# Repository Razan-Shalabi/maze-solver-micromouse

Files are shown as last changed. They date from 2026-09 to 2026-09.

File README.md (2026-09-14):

# Toots — Autonomous Micromouse Robot

An autonomous maze-solving robot built on an ESP32, using a floodfill algorithm, PID-corrected motor control, and time-of-flight wall sensing to navigate an 8×8 maze without human input.

**Team:** Razan Shalabi, Shatha Abualrub, Lara Daifallah, Ghada Swalha

**Instructor:** Wasel Ghanem

**Institution:** Birzeit University

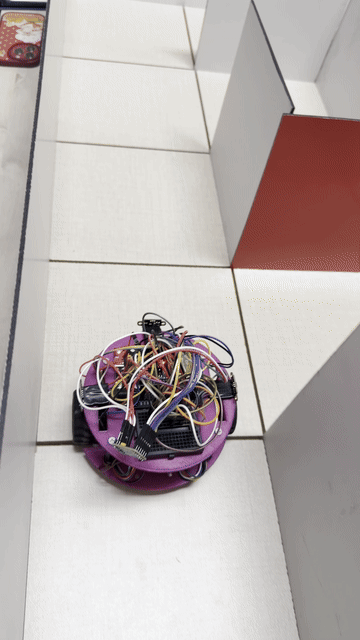
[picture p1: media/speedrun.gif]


*Toots completing a speed-run pass after the exploration phase.*

## Overview

Toots explores an 8×8 maze, builds a map of its walls, and computes the shortest path to the center. It then executes that path at higher speed on a return run. Core capabilities:

- Real-time wall detection using three VL53L0X time-of-flight sensors
- Wheel odometry via interrupt-driven magnetic encoders
- Shortest-path planning with a floodfill (BFS) solver
- PID-corrected differential drive to maintain heading between walls
- A web dashboard, served directly from the ESP32, for live monitoring and parameter tuning

## Documentation

| Resource | Description |
|---|---|
| [`hardware/README.md`](hardware/README.md) | Full parts list, pin map, and per-component wiring notes |
| [`hardware/3d-models/`](hardware/3d-models/README.md) | Chassis STL file and Fusion 360 source |
| [`software/README.md`](software/README.md) | Firmware architecture, run modes, dashboard API, tunable parameters |
| [Trello board](https://trello.com/invite/b/69e2683745c4a1b255d148a3/ATTI001aa2c3a295a99a65e10da04925d9e88B10C430/interface-project) | Full project build log |

## Hardware Summary

| Component | Part | Role |
|---|---|---|
| MCU | ESP32 Dev Kit | Runs firmware and web dashboard |
| Motor driver | DRV8833 | Drives both motors |
| Motors | N20 DC with magnetic encoder, 6V, 530 RPM | Differential drive with speed feedback |
| Distance sensors | VL53L0X ×3 | Front, left, right wall detection |
| Chassis | Custom 3D-printed | Sized to maze cell constraints |

Full specifications and wiring: [`hardware/README.md`](hardware/README.md)

## How It Works

**Wall sensing.** Three ToF sensors feed a correction function that keeps the robot centered between walls, or at a fixed offset from a single wall, while driving forward.

**Motion tracking.** Interrupt-driven encoder ticks on both wheels are compared through a PID loop to keep the two motors synchronized.

**Path planning.** A floodfill (BFS) solver computes the shortest path to the maze center as the robot explores, and recomputes as new walls are discovered.

**Connectivity.** WiFi credentials are never hardcoded. On first boot, the ESP32 opens a setup access point (`TOOTs-Setup`); the operator selects a network and enters credentials once, which are then stored to flash.

**Monitoring.** A dashboard served at `http://toots.local` shows live sensor data, current position, and run mode, with controls to tune PID, turn timing, and wall-following parameters without re-flashing.

Full technical detail: [`software/README.md`](software/README.md)

## Getting Started

**Requirements:**
- Arduino IDE with the ESP32 board package
- Libraries: `WiFiManager` (tzapu), `VL53L0X`, `ESPmDNS` (bundled with the ESP32 core)

**Steps:**
1. Open `software/toots.ino` in the Arduino IDE
2. Select the correct ESP32 board and port
3. Upload
4. On first boot, connect to the `TOOTs-Setup` network and enter your WiFi credentials
5. Open `http://toots.local` (or the IP shown in Serial output) to access the dashboard

## Repository Structure

```
maze-solver-micromouse/
├── README.md
├── media/
│   └── speedrun.gif
├── software/
│   ├── README.md
│   └── toots.ino
└── hardware/
    ├── README.md
    ├── components/
    └── 3d-models/
```

## Background

The project began with component selection and procurement, followed by chassis design in Fusion 360, built to fit within maze cell constraints while keeping weight low enough not to strain the motors. The chassis was 3D-printed and assembled alongside firmware development.

The floodfill solving logic was validated in simulation before deployment to hardware, to confirm correctness of the algorithm independent of sensor noise or mechanical variance.

A full build log, including design decisions and iteration history, is maintained on the [Trello board](https://trello.com/invite/b/69e2683745c4a1b255d148a3/ATTI001aa2c3a295a99a65e10da04925d9e88B10C430/interface-project).

## License

Submitted as academic coursework. The code is available to study and reference.

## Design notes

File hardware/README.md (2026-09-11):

# Hardware

Toots is built around an ESP32, driving two N20 motors through a DRV8833, sensing walls with three VL53L0X ToF sensors, and tracking movement with magnetic wheel encoders.

## Components

| Photo | Component | Part | Role | Docs |
|---|---|---|---|---|
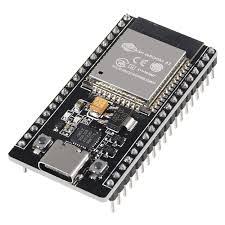
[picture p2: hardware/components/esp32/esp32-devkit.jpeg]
|  | MCU | ESP32 Dev Kit (30-pin) | Runs firmware + web dashboard | [→](components/esp32/README.md) |
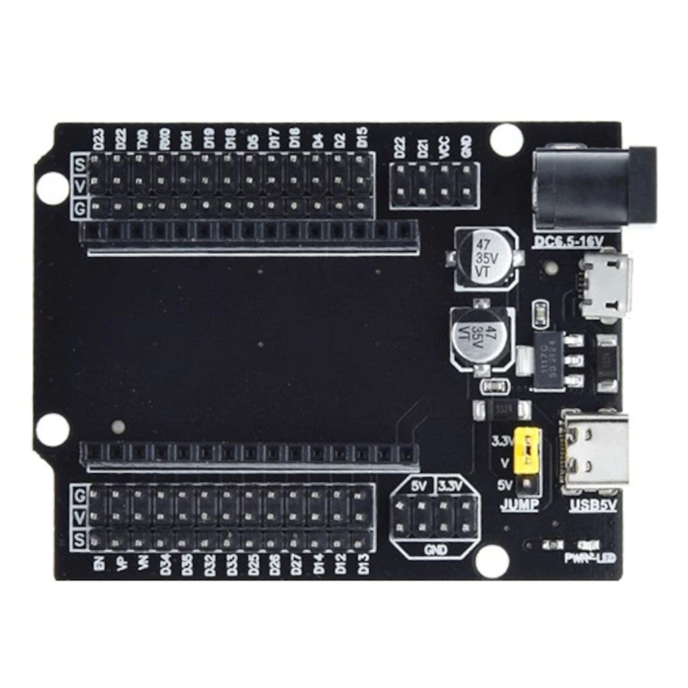
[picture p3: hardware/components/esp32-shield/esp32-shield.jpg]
|  | Expansion Board | ESP32 30-pin Shield | Breaks out GPIO for wiring | [→](components/esp32-shield/README.md) |
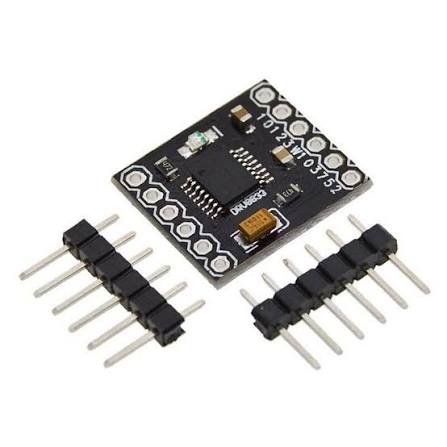
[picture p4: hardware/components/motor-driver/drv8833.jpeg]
|  | Motor Driver | DRV8833 (2-channel) | Drives both N20 motors | [→](components/motor-driver/README.md) |
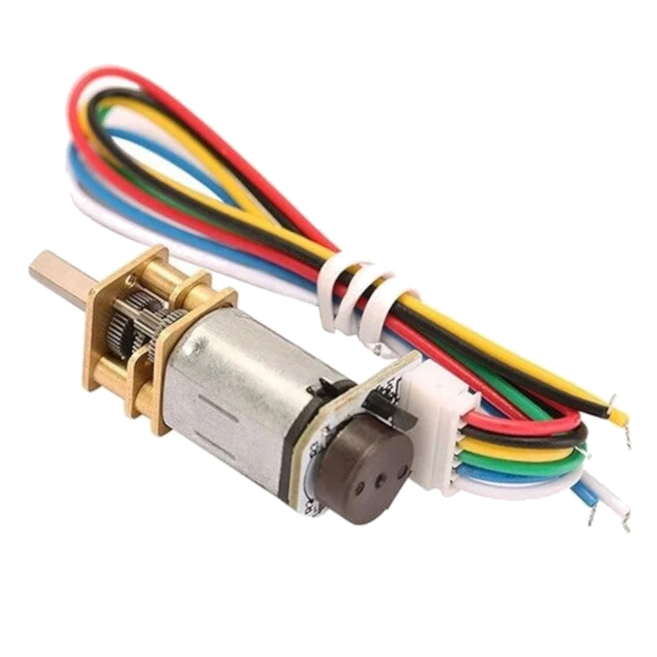
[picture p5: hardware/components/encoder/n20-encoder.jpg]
|  | Motors | N20 DC w/ Encoder, 6V 530 RPM | Differential drive + speed feedback | [→](components/encoder/README.md) |
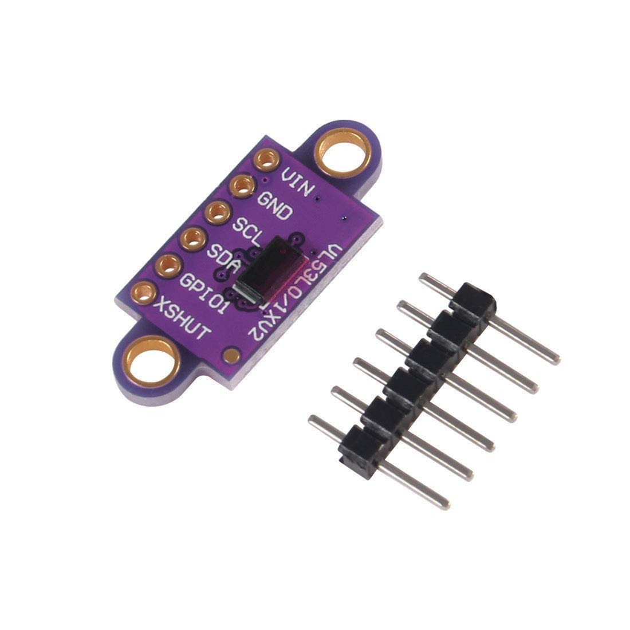
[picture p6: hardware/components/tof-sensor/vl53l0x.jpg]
|  | ToF Sensors ×3 | VL53L0X | Wall detection: front, left, right | [→](components/tof-sensor/README.md) |
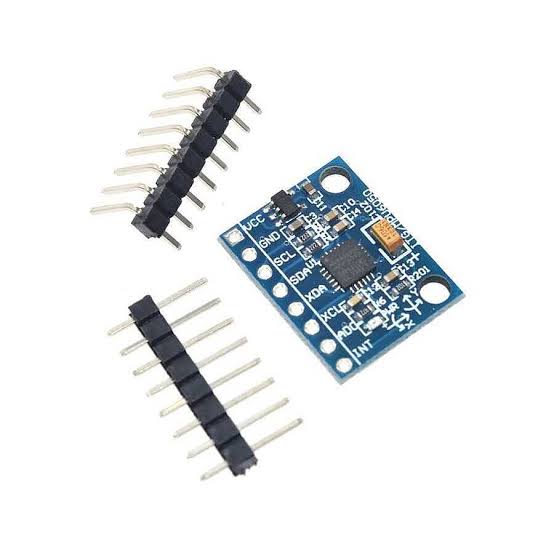
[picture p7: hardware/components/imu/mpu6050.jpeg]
|  | IMU | MPU-6050 | On board, not yet used in firmware | [→](components/imu/README.md) |
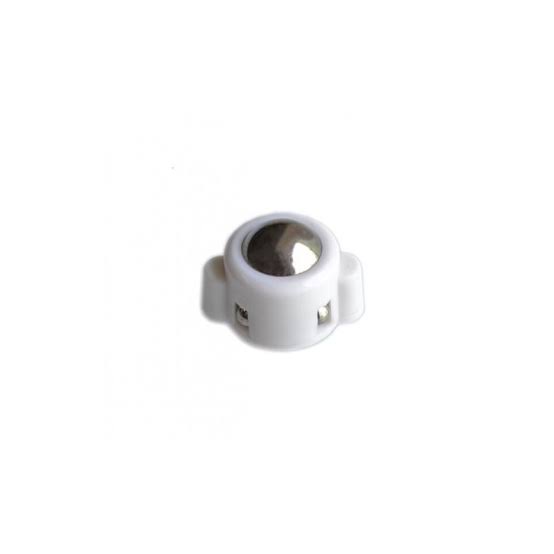
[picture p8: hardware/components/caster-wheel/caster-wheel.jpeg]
|  | Caster Wheel | Small Ball Caster | Third point of contact | [→](components/caster-wheel/README.md) |
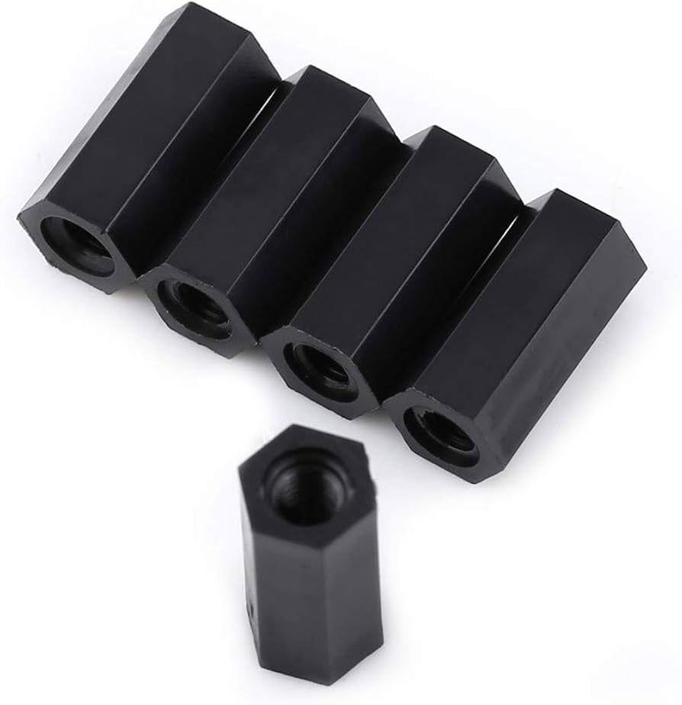
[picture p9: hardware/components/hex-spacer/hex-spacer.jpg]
|  | Standoffs | M3 Nylon Hex Spacer | Chassis layer mounting | [→](components/hex-spacer/README.md) |
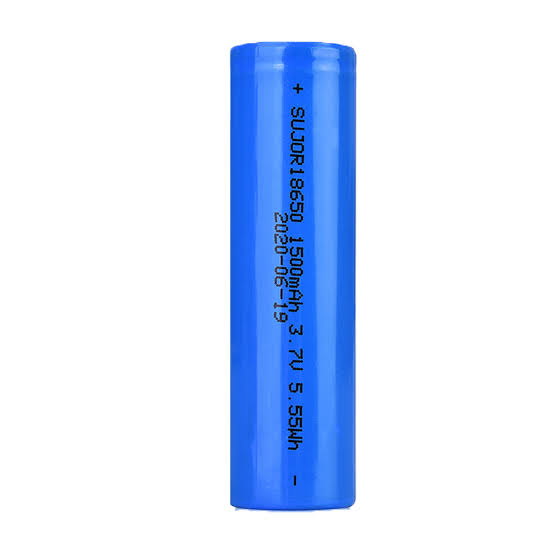
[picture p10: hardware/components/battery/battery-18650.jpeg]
|  | Battery | 18650 Li-ion | Main power | [→](components/battery/README.md) |
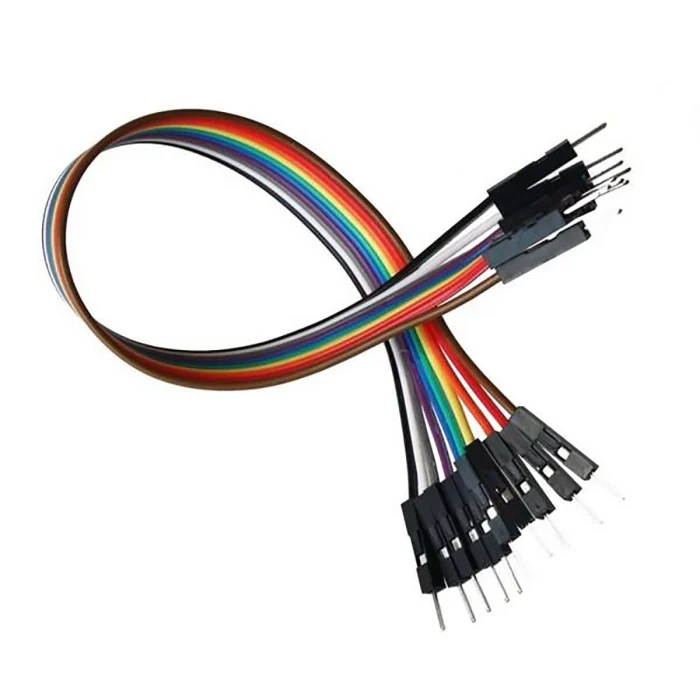
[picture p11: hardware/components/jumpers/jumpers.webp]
|  | Wiring | Jumper Wires | Sensor & module connections | [→](components/jumpers/README.md) |

## Pin Map

| Function | GPIO |
|---|---|
| Left motor IN1 / IN2 | 14 / 12 |
| Right motor IN3 / IN4 | 13 / 15 |
| Left encoder C1 / C2 | 34 / 35 |
| Right encoder C1 / C2 | 32 / 33 |
| ToF I2C SDA / SCL | 21 / 22 |
| ToF Front / Left / Right XSHUT | 25 / 26 / 27 |

Click into any component above for wiring details, how it's used in the code, specs, and troubleshooting.

## 3D Models

The chassis STL and Fusion 360 source link are in [`3d-models/`](3d-models/README.md).

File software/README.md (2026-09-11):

# Software

Single-file ESP32 firmware (`toots.ino`) written in C++ with the Arduino framework. It handles sensing, motor control, maze solving, and serves a live web dashboard — all from one sketch.

## Run Modes

The robot operates as a state machine (`RunMode`), driven from `solverStep()` in the main loop:

| Mode | Trigger | What it does |
|---|---|---|
| `MODE_IDLE` | Default / after any run finishes | Motors stopped, waiting for a command |
| `MODE_SOLVE` | `solve` command | Explores the maze, mapping walls with floodfill as it goes |
| `MODE_RETURN` | `return` command | Floods back to the start cell |
| `MODE_SPEEDRUN` | `speedrun` command (requires a completed map + robot at start) | Runs the shortest known path at full speed |

## Core Logic

- **`getWallCorrection()`** — compares left/right ToF readings against `WALL_THRESHOLD` and `SIDE_TARGET_MM` to compute a steering correction, keeping the robot centered (or a fixed distance from one wall)
- **`moveContinuousForward()`** — the main driving loop: reads encoders, computes error between wheels, runs it through a PID controller (`Kp`, `Ki`, `Kd`), adds the wall correction and a fixed motor bias (`BASE_CORRECTION`), then calls `setMotor()`
- **`floodFill(toStart, onlyVisited)`** — BFS distance-field solver; recomputes as new walls are discovered
- **`turnLeft90()` / `turnRight90()` / `turn180()`** — time-based turns using calibrated delays, followed by `postTurnCalibration()` to re-align using side wall distances

## Web Dashboard API

Served from the ESP32 itself — no external server needed.

| Endpoint | Method | Purpose |
|---|---|---|
| `/` | GET | Serves the dashboard HTML/CSS/JS |
| `/data` | GET | Returns live JSON: position, sensor readings, mode, all tunable parameters |
| `/cmd?c=...` | GET | Sends a command — see table below |
| `/set?k=...&v=...` | GET | Live-tunes a parameter without re-flashing |

**Commands (`/cmd?c=`):**

| Command | Effect |
|---|---|
| `solve` | Start maze exploration |
| `return` | Return to start cell |
| `speedrun` | Run the fastest known path |
| `s` | Emergency stop |
| `startfwd` / `stopfwd` | Manual continuous forward drive |
| `left90` / `right90` / `turn180` | Manual single turn |
| `celltof` | Move forward exactly one cell |
| `reset` | Zero the encoders |
| `resetpose` | Reset (x, y, direction) to origin |
| `resetmaze` | Clear the entire wall map |
| `debug` | Plain-text status dump over HTTP |

## Tunable Parameters

All adjustable live via the dashboard (`/set`), no re-upload needed:

| Parameter | Default | Role |
|---|---|---|
| `BASE_SPEED` | 120 | Cruising motor speed |
| `MIN_SPEED` | 58 | Floor speed after correction |
| `TURN_SPEED` | 120 | Speed during turns |
| `Kp` / `Ki` / `Kd` | 3.0 / 0.005 / 0.5 | PID gains for straight-line motor sync |
| `BASE_CORRECTION` | 3 | Fixed bias compensating for motor mismatch |
| `TURN_DELAY_LEFT` / `RIGHT` / `180` | 700 / 435 / 790 ms | Calibrated turn durations |
| `CELL_TICKS` | 250 | Encoder ticks per maze cell |
| `WALL_THRESHOLD` | 200 mm | Distance below which a wall is "detected" |
| `FRONT_STOP` | 100 mm | Distance to treat front as blocked |
| `SIDE_TARGET_MM` | 45 mm | Target distance from a single side wall |
| `LEFT_OFFSET` / `RIGHT_OFFSET` | -70 / -10 | Per-sensor calibration offsets |

## Known Limitations / Next Steps

- **Single monolithic file** — all logic lives in one `.ino`. Splitting sensing, motor control, and maze-solving into separate modules (`.h`/`.cpp` files) would make it easier to test and extend.
- **MPU-6050 not yet integrated** — the IMU is on the board but unused; turns currently rely on fixed time delays + post-turn wall calibration rather than gyro feedback. Adding gyro-based heading correction is a natural next step to reduce drift.
- **No automated tests** — all tuning and validation happens live via the dashboard.

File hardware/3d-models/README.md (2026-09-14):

# 3D Models — Chassis

The robot's chassis was designed in-house in Fusion 360 and 3D-printed.

- **STL file:** [chassis.stl](chassis.stl) — ready to slice and print
- **Fusion 360 source (editable):** [View on Fusion 360](https://student395829.autodesk360.com/g/shares/SH28cd1QT2badd0ea72bd2512c9273c0f380)

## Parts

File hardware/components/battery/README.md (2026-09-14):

# Power: 18650 Li-ion Battery + Charger


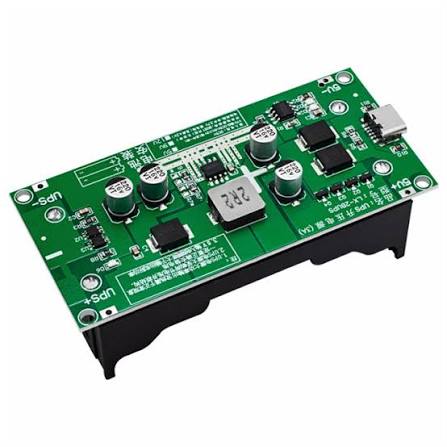
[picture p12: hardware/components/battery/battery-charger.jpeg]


## What is this?

Main power source for the robot, plus the module used to recharge it.

## Specs

- **Battery:** Li-ion 18650 cell
- **Charger:** Type-C, 15W, 3A charging module

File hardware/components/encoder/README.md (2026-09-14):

# N20 Magnetic Encoder



## What is this?

Reads wheel rotation from the N20 motors' built-in magnetic encoders using hardware interrupts. Used for distance tracking (how far each wheel has turned) and forward-motion PID correction.

## Hardware Connections

| Pin | Connects to | Role |
|---|---|---|
| C1 (Left) | ESP32 GPIO 34 | Main counting pin (interrupt on RISING) |
| C2 (Left) | ESP32 GPIO 35 | Direction detection |
| C1 (Right) | ESP32 GPIO 32 | Main counting pin (interrupt on RISING) |
| C2 (Right) | ESP32 GPIO 33 | Direction detection |
| VCC | 3.3V | Power |
| GND | Ground | Ground |

## How It Works

Interrupt-based counting — no polling:

```cpp
void IRAM_ATTR leftEncoderISR() {
  if (digitalRead(ENC_LEFT_C2) == HIGH)
    leftTicks++;
  else
    leftTicks--;
}
```

- Every rising edge on C1 fires the interrupt
- C2's state at that moment tells us the rotation direction (increments or decrements `leftTicks`/`rightTicks`)
- `resetEncoders()` zeroes both counters (used at the start of every move)

Ticks are read safely mid-motion by briefly disabling interrupts:

```cpp
noInterrupts();
dL = leftTicks;
dR = rightTicks;
interrupts();
```

## Specifications

- **Encoder resolution:** 530 PPR (pulses per revolution)
- **Motor:** N20 DC, 6V, 530 RPM

## Used In

- `moveContinuousForward()` — encoder difference (`dL + dR`) feeds the PID loop to keep both wheels in sync
- `CELL_TICKS` (currently `250`) — how many ticks equal one maze cell of forward travel

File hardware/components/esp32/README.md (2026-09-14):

# ESP32 Dev Kit (30-pin)



## What is this?

The brain of Toots — a dual-core microcontroller with built-in WiFi. It runs the maze-solving logic, drives the motors, reads all sensors, and hosts a live web dashboard for monitoring and tuning.

## Role in the System

- Runs the main control loop (`solverStep()`) — sensing, PID correction, floodfill decisions
- Hosts a `WebServer` on port 80 serving a live dashboard (position, sensor readings, tunable parameters)
- Connects to WiFi via **WiFiManager** — no hardcoded credentials. On first boot (or after a reset) it opens its own setup access point (`TOOTs-Setup`); connecting to that AP lets you pick your home WiFi and enter the password once, which is then saved to flash
- Reachable at `http://toots.local` via mDNS, or by IP shown in Serial output

## Hardware Connections

All sensor and motor pins connect here — see each component's own page (`encoder/`, `motor-driver/`, `tof-sensor/`) for exact pin numbers.

## Used In

- `setup()` — initializes motors, encoders, ToF sensors, WiFi, and the web server
- `loop()` — handles incoming web requests and runs the active solve/return/speedrun mode every 20ms

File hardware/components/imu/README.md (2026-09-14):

# MPU-6050 (Gyroscope + Accelerometer)



## What is this?

A 6-DoF IMU (gyroscope + accelerometer), included in the build for heading tracking.

This sensor is part of the hardware but **isn't wired into `toots.ino`'s logic yet** — the current heading/turn control relies entirely on the ToF wall-following (`getWallCorrection()`) and calibrated turn delays (`TURN_DELAY_LEFT`, `TURN_DELAY_RIGHT`, `TURN_DELAY_180`), not gyroscope data.

It's documented here for completeness and as a planned upgrade — adding gyro-based heading correction would reduce drift during turns compared to fixed time delays.

## Hardware Connections

| Pin | Connects to |
|---|---|
| SDA | ESP32 GPIO 21 (shared I2C bus with ToF sensors) |
| SCL | ESP32 GPIO 22 (shared I2C bus with ToF sensors) |
| VCC | 3.3V |
| GND | Ground |

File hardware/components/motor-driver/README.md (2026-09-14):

# DRV8833 Motor Driver



## What is this?

A 2-channel H-bridge driver that lets the ESP32 (3.3V logic) control both N20 motors independently — forward, reverse, and speed via PWM — since the ESP32's GPIO pins can't drive motors directly.

## Hardware Connections

| DRV8833 Pin | Connects to | Role |
|---|---|---|
| IN1 | ESP32 GPIO 14 | Left motor, direction A |
| IN2 | ESP32 GPIO 12 | Left motor, direction B |
| IN3 | ESP32 GPIO 13 | Right motor, direction A |
| IN4 | ESP32 GPIO 15 | Right motor, direction B |

## How It Works

```cpp
void setMotor(int leftSpeed, int rightSpeed) {
  rightSpeed = -rightSpeed;   // right motor is mounted flipped
  leftSpeed  = constrain(leftSpeed,  -255, 255);
  rightSpeed = constrain(rightSpeed, -255, 255);

  if (leftSpeed > 0)      { analogWrite(IN1, leftSpeed); analogWrite(IN2, 0); }
  else if (leftSpeed < 0) { analogWrite(IN1, 0); analogWrite(IN2, -leftSpeed); }
  else                    { analogWrite(IN1, 0); analogWrite(IN2, 0); }

  // same pattern for IN3/IN4 with rightSpeed
}
```

- Each wheel is driven by a pair of pins — PWM goes on whichever pin matches the desired direction, the other pin goes LOW
- Speed range is `-255` to `255` (negative = reverse)
- `rightSpeed` is inverted before use because the right motor is physically mounted in the opposite orientation to the left one — without this flip, "forward" on the right wheel would spin it backward

## Used In

- `setMotor(leftSpeed, rightSpeed)` is the single point everything else calls — PID output, wall correction, and turning all funnel through it
- `stopMotorsOnly()` → `setMotor(0, 0)`

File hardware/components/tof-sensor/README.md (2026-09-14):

# VL53L0X Time-of-Flight Sensors (×3)



## What is this?

Three laser-based distance sensors (front, left, right) that detect maze walls. They share one I2C bus, so each is given a unique address at boot.

## Hardware Connections

| Pin | Connects to | Role |
|---|---|---|
| SDA (all 3) | ESP32 GPIO 21 | Shared I2C data line |
| SCL (all 3) | ESP32 GPIO 22 | Shared I2C clock line |
| XSHUT (Front) | ESP32 GPIO 25 | Power-down control, used to assign address |
| XSHUT (Left) | ESP32 GPIO 26 | Power-down control, used to assign address |
| XSHUT (Right) | ESP32 GPIO 27 | Power-down control, used to assign address |

## How It Works

**Startup — assigning unique addresses:**

All VL53L0X sensors boot with the same default I2C address, so they can't just be wired in parallel and read directly. `setupToFs()` gets around this:

1. Pull all three XSHUT pins LOW (all sensors off)
2. Bring one sensor's XSHUT HIGH, initialize it, and reassign its I2C address (front → `0x30`, left → `0x31`, right → `0x32`)
3. Repeat for the next sensor

**Reading:**

```cpp
void readToFs() {
  int f = tofFront.readRangeContinuousMillimeters();
  ...
  if (tofFront.timeoutOccurred() || f <= 0 || f > 2000) {
    f = 2000;  // treat invalid reading as "no wall in range"
  }
  ...
}
```

`readToFsAveraged()` takes 3 readings 20ms apart and averages them for more stable values, used before turns.

## Used In

- `leftWall()`, `frontWall()`, `rightWall()` — compare distance against `WALL_THRESHOLD` (`200`mm)
- `getWallCorrection()` — steers the robot to stay centered between walls (or a fixed distance from a single wall) while driving forward
- Floodfill mapping — wall presence per cell is recorded from these readings

## Specifications

- **Front stop distance:** `FRONT_STOP` = 100mm 
- **Wall detection threshold:** `WALL_THRESHOLD` = 200mm
- **Side wall target distance:** `SIDE_TARGET_MM` = 45mm

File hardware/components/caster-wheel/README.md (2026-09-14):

# Small Ball Caster Wheel



## What is this?

A free-rolling ball caster used as the robot's third point of contact, opposite the two driven N20 wheels. Provides stable support without adding friction or needing its own motor.

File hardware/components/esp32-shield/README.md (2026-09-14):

# ESP32 30-Pin Expansion Board



## What is this?

A breakout/prototyping shield that sits under the ESP32 dev kit, breaking each GPIO pin out to a more accessible screw terminal or header — makes wiring the motor driver, encoders, and sensors more secure than jumping directly off the ESP32's pins.

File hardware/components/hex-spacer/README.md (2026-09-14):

# M3 Nylon Hex Spacer



## What is this?

Standoffs used to mount and space the chassis layers (e.g. separating the main board layer from the sensor/battery layer). M3 thread, female-to-female.

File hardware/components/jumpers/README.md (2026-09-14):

# Jumper Wires



## What is this?

Used for all point-to-point wiring between the ESP32, motor driver, encoders, and ToF sensors.

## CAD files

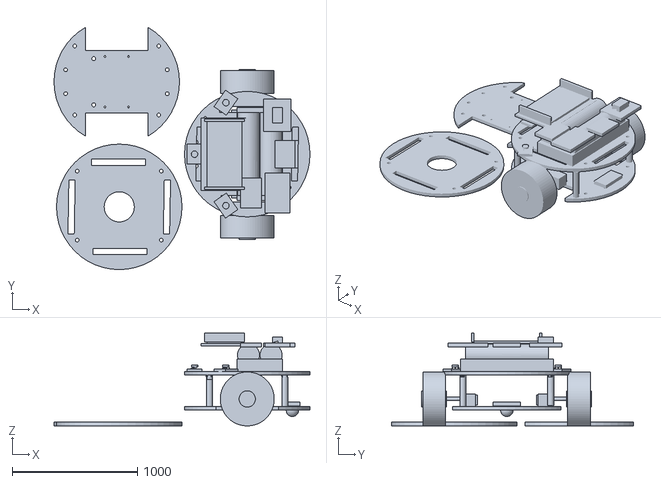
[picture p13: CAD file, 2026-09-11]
hardware/3d-models/chassis.stl
2040.0 x 1930.0 x 740.0

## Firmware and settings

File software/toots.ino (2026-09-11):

#include <WiFi.h>
#include <WebServer.h>
#include <Wire.h>
#include <VL53L0X.h>
#include <WiFiManager.h>   // https://github.com/tzapu/WiFiManager - captive portal WiFi setup
#include <ESPmDNS.h>       // built into ESP32 core - lets users reach the robot at http://toots.local

// maze size
#define MAZE_SIZE 8

// ===== WIFI SETUP (WiFiManager) 
// On first boot (or after a WiFi reset) the ESP32 opens its own access point called "TOOTs-Setup".
// Connect a phone or laptop to that AP, a setup page will pop up (or go to 192.168.4.1), pick your home WiFi network from the list, enter the
// password, and the ESP32 will save it to flash and reboot onto your
// network automatically. Every future boot will reconnect on its own.
const char* AP_SETUP_NAME = "TOOTs-Setup";
const char* MDNS_HOSTNAME = "toots"; // reachable at http://toots.local

WebServer server(80);

// tof pins
#define TOF_SDA     21
#define TOF_SCL     22
#define FRONT_XSHUT 25
#define LEFT_XSHUT  26
#define RIGHT_XSHUT 27
#define FRONT_ADDR  0x30
#define LEFT_ADDR   0x31
#define RIGHT_ADDR  0x32
VL53L0X tofFront;
VL53L0X tofLeft;
VL53L0X tofRight;
int leftDist  = 500;
int frontDist = 500;
int rightDist = 500;

// motor pins
#define IN1 14
#define IN2 12
#define IN3 13
#define IN4 15

// encoders pins
#define ENC_LEFT_C1  34
#define ENC_LEFT_C2  35
#define ENC_RIGHT_C1 32
#define ENC_RIGHT_C2 33

// encoders
volatile long leftTicks  = 0;
volatile long rightTicks = 0;

void IRAM_ATTR leftEncoderISR() {
  if (digitalRead(ENC_LEFT_C2) == HIGH)
    leftTicks++;
  else
    leftTicks--;
}

void IRAM_ATTR rightEncoderISR() {
  if (digitalRead(ENC_RIGHT_C2) == HIGH)
    rightTicks++;
  else
    rightTicks--;
}

// tunable parameters
int   BASE_SPEED     = 120;
int   MIN_SPEED      = 58;
int   MAX_CORRECTION = 50;
int   BASE_CORRECTION = 3;

// sensor calibration
int   LEFT_OFFSET  = -70;
int   RIGHT_OFFSET = -10;

// WALL CORRECTION PARAMETERS
int   SIDE_TARGET_MM   = 45;
int   WALL_CORR_STRENGTH = 2;
int   WALL_CORR_LIMIT  = 15;

// PID VALUES
float Kp = 3.0;
float Ki = 0.005;
float Kd = 0.5;

// TURN CALIBRATION
int   TURN_SPEED        = 120;
int   TURN_DELAY_LEFT   = 700;
int   TURN_DELAY_RIGHT  = 435;
int   TURN_DELAY_180    = 790;

// CELL CALIBRATION
long  CELL_TICKS     = 250;
int   WALL_THRESHOLD = 200;
int   FRONT_STOP     = 100;

// MAZE VARIABLES
#define MAZE MAZE_SIZE
uint8_t wallsGrid[MAZE][MAZE];
bool    visitedGrid[MAZE][MAZE];
uint8_t floodGrid[MAZE][MAZE];
uint8_t pathGrid[MAZE][MAZE];

int robotX   = 0;
int robotY   = 0;
int robotDir = 0;

int startX = 0;
int startY = 0;
int startDir = 0;

const int DX[4] = { 0, 1, 0, -1 };
const int DY[4] = { 1, 0, -1, 0 };

enum RunMode { MODE_IDLE, MODE_SOLVE, MODE_RETURN, MODE_SPEEDRUN };
RunMode runMode = MODE_IDLE;

bool mazeMapped = false;
bool abortFlag    = false;
bool motionActive = false;
bool continuousForward = false;
String statusText   = "READY";
String lastDecision = "-";
int    decisionSeq  = 0;

// FORWARD DECLARATIONS
void startMode(RunMode m);
void stopEverything();
void logDecision(String d);
void wallAlignment();
void postTurnCalibration();
int getBestDirection();

// ENCODER HELPERS
void resetEncoders() {
  noInterrupts();
  leftTicks = 0;
  rightTicks = 0;
  interrupts();
}

// MOTORS
void setMotor(int leftSpeed, int rightSpeed) {
  rightSpeed = -rightSpeed;
  leftSpeed  = constrain(leftSpeed,  -255, 255);
  rightSpeed = constrain(rightSpeed, -255, 255);

  if (leftSpeed > 0) {
    analogWrite(IN1, leftSpeed);
    analogWrite(IN2, 0);
  } else if (leftSpeed < 0) {
    analogWrite(IN1, 0);
    analogWrite(IN2, -leftSpeed);
  } else {
    analogWrite(IN1, 0);
    analogWrite(IN2, 0);
  }

  if (rightSpeed > 0) {
    analogWrite(IN3, rightSpeed);
    analogWrite(IN4, 0);
  } else if (rightSpeed < 0) {
    analogWrite(IN3, 0);
    analogWrite(IN4, -rightSpeed);
  } else {
    analogWrite(IN3, 0);
    analogWrite(IN4, 0);
  }
}

void stopMotorsOnly() { setMotor(0, 0); }

// TOF FUNCTIONS
void setupToFs() {
  pinMode(FRONT_XSHUT, OUTPUT);
  pinMode(LEFT_XSHUT,  OUTPUT);
  pinMode(RIGHT_XSHUT, OUTPUT);

  // Turn off all sensors first
  digitalWrite(FRONT_XSHUT, LOW);
  digitalWrite(LEFT_XSHUT,  LOW);
  digitalWrite(RIGHT_XSHUT, LOW);
  delay(20);

  // Start front sensor
  digitalWrite(FRONT_XSHUT, HIGH);
  delay(20);

  if (!tofFront.init()) {
    Serial.println("ERROR: Front ToF sensor not detected");
  } else {
    tofFront.setAddress(FRONT_ADDR);
    tofFront.setTimeout(100);
    tofFront.startContinuous(20);
    Serial.println("Front ToF ready");
  }

  // Start left sensor
  digitalWrite(LEFT_XSHUT, HIGH);
  delay(20);

  if (!tofLeft.init()) {
    Serial.println("ERROR: Left ToF sensor not detected");
  } else {
    tofLeft.setAddress(LEFT_ADDR);
    tofLeft.setTimeout(100);
    tofLeft.startContinuous(20);
    Serial.println("Left ToF ready");
  }

  // Start right sensor
  digitalWrite(RIGHT_XSHUT, HIGH);
  delay(20);

  if (!tofRight.init()) {
    Serial.println("ERROR: Right ToF sensor not detected");
  } else {
    tofRight.setAddress(RIGHT_ADDR);
    tofRight.setTimeout(100);
    tofRight.startContinuous(20);
    Serial.println("Right ToF ready");
  }
}

void readToFs() {
  int f = tofFront.readRangeContinuousMillimeters();
  int l = tofLeft.readRangeContinuousMillimeters();
  int r = tofRight.readRangeContinuousMillimeters();

  // Front sensor reading check
  if (tofFront.timeoutOccurred() || f <= 0 || f > 2000) {
    f = 2000;
  }

  // Left sensor reading check
  if (tofLeft.timeoutOccurred() || l <= 0 || l > 2000) {
    l = 2000;
  } else {
    l += LEFT_OFFSET;

    if (l < 0) {
      l = 0;
    }
  }

  // Right sensor reading check
  if (tofRight.timeoutOccurred() || r <= 0 || r > 2000) {
    r = 2000;
  } else {
    r += RIGHT_OFFSET;

    if (r < 0) {
      r = 0;
    }
  }

  frontDist = f;
  leftDist  = l;
  rightDist = r;
}

void readToFsAveraged() {
  long sl = 0, sf = 0, sr = 0;
  for (int i = 0; i < 3; i++) {
    readToFs();
    sl += leftDist; sf += frontDist; sr += rightDist;
    delay(20);
  }
  leftDist = sl/3; frontDist = sf/3; rightDist = sr/3;
}

bool leftWall()  { return leftDist  < WALL_THRESHOLD; }
bool frontWall() { return frontDist < WALL_THRESHOLD; }
bool rightWall() { return rightDist < WALL_THRESHOLD; }

// GET WALL CORRECTION
int getWallCorrection() {
  int wallCorr = 0;
  bool hasLeftWall = (leftDist < WALL_THRESHOLD);
  bool hasRightWall = (rightDist < WALL_THRESHOLD);

  if (hasLeftWall && hasRightWall) {
    int error = leftDist - rightDist;
    wallCorr = error / WALL_CORR_STRENGTH;
  } else if (hasLeftWall) {
    int error = leftDist - SIDE_TARGET_MM;
    wallCorr = error / WALL_CORR_STRENGTH;
  } else if (hasRightWall) {
    int error = SIDE_TARGET_MM - rightDist;
    wallCorr = error / WALL_CORR_STRENGTH;
  }

  wallCorr = constrain(wallCorr, -WALL_CORR_LIMIT, WALL_CORR_LIMIT);
  return wallCorr;
}

// POST-TURN CALIBRATION
void postTurnCalibration() {
  Serial.println("=== POST-TURN CALIBRATION ===");

  stopMotorsOnly();
  delay(150);

  const int MAX_ATTEMPTS = 3;
  const int ERROR_TOLERANCE = 3;
  const int CALIBRATION_SPEED = 55;

  for (int attempt = 0; attempt < MAX_ATTEMPTS; attempt++) {
    readToFsAveraged();

    bool hasLeftWall  = leftDist  < WALL_THRESHOLD;
    bool hasRightWall = rightDist < WALL_THRESHOLD;

    Serial.print("Attempt: ");
    Serial.print(attempt + 1);

    Serial.print(" | Left: ");
    Serial.print(leftDist);

    Serial.print(" mm | Right: ");
    Serial.println(rightDist);

    int correction = 0;

    // Robot is between two walls
    if (hasLeftWall && hasRightWall) {
      correction = leftDist - rightDist;
    }

    // Only left wall exists
    else if (hasLeftWall) {
      correction = leftDist - SIDE_TARGET_MM;
    }

    // Only right wall exists
    else if (hasRightWall) {
      correction = SIDE_TARGET_MM - rightDist;
    }

    // No side walls, so ToF calibration is not possible
    else {
      Serial.println("No side walls available for calibration");
      return;
    }

    correction /= WALL_CORR_STRENGTH;

    correction = constrain(
      correction,
      -WALL_CORR_LIMIT,
      WALL_CORR_LIMIT
    );

    Serial.print("Correction: ");
    Serial.println(correction);

    // Calibration is good enough
    if (abs(correction) <= ERROR_TOLERANCE) {
      Serial.println("Post-turn calibration completed");
      break;
    }

    // Small pivot instead of moving forward
    if (correction > 0) {
      setMotor(-CALIBRATION_SPEED, CALIBRATION_SPEED);
    } else {
      setMotor(CALIBRATION_SPEED, -CALIBRATION_SPEED);
    }

    // Small correction pulse
    int pulseTime = abs(correction) * 3;
    pulseTime = constrain(pulseTime, 15, 60);

    delay(pulseTime);

    stopMotorsOnly();
    delay(100);
  }

  stopMotorsOnly();
  readToFsAveraged();

  Serial.print("Final Left: ");
  Serial.print(leftDist);

  Serial.print(" mm | Final Right: ");
  Serial.print(rightDist);

  Serial.println(" mm");
}

// WALL ALIGNMENT AFTER CELL
void wallAlignment() {
  stopMotorsOnly();
  delay(100);

  readToFsAveraged();

  bool hasLeftWall  = leftDist  < WALL_THRESHOLD;
  bool hasRightWall = rightDist < WALL_THRESHOLD;

  Serial.print("Left: ");
  Serial.print(leftDist);
  Serial.print(" mm | Right: ");
  Serial.print(rightDist);
  Serial.print(" mm | ");

  if (hasLeftWall && hasRightWall) {
    int error = leftDist - rightDist;

    Serial.print("Both walls | Center error: ");
    Serial.println(error);

  } else if (hasLeftWall) {
    int error = leftDist - SIDE_TARGET_MM;

    Serial.print("Left wall | Distance error: ");
    Serial.println(error);

  } else if (hasRightWall) {
    int error = SIDE_TARGET_MM - rightDist;

    Serial.print("Right wall | Distance error: ");
    Serial.println(error);

  } else {
    Serial.println("No side walls");
  }
}

// CONTINUOUS FORWARD
void moveContinuousForward() {
  continuousForward = true;
  motionActive = true;
  statusText = "CONTINUOUS FWD";

  resetEncoders();

  float prevError = 0;
  float integral = 0;
  float lastError = 0;

  while (continuousForward && !abortFlag) {
    server.handleClient();
    readToFs();

    long dL;
    long dR;

    // Read encoder values safely
    noInterrupts();
    dL = leftTicks;
    dR = rightTicks;
    interrupts();

    int wallCorr = getWallCorrection();

    float error = dL + dR;

    // Ignore very small encoder differences
    if (abs(error) < 3) {
      error = 0;
    }

    // Reset integral if the error direction changes
    if (error * lastError < 0) {
      integral = 0;
    }

    lastError = error;

    // Calculate and limit integral
    integral += error;
    integral = constrain(integral, -20.0f, 20.0f);

    // Calculate derivative
    float derivative = error - prevError;

    // PID + motor bias + wall correction
    float correction =
        (Kp * error) +
        (Ki * integral) +
        (Kd * derivative) +
        BASE_CORRECTION +
        wallCorr;

    correction = constrain(
        correction,
        -(float)MAX_CORRECTION,
        (float)MAX_CORRECTION
    );

    int leftSpeed = constrain(
        BASE_SPEED - (int)correction,
        MIN_SPEED,
        255
    );

    int rightSpeed = constrain(
        BASE_SPEED + (int)correction,
        MIN_SPEED,
        255
    );

    setMotor(leftSpeed, rightSpeed);

    prevError = error;

    delay(20);
  }

  stopMotorsOnly();
  motionActive = false;
  statusText = "STOPPED";
}

// ===== MOVEMENT - ONE CELL =====
bool moveOneCell() {
  stopMotorsOnly();
  delay(100);

  resetEncoders();

  motionActive = true;
  statusText = "MOVING";

  bool arrived = false;

  float prevError = 0.0;
  float integral = 0.0;
  float lastError = 0.0;

  int debugCount = 0;

  while (!abortFlag) {
    server.handleClient();
    readToFs();

    long dL;
    long dR;

    // Read both encoders safely
    noInterrupts();
    dL = leftTicks;
    dR = rightTicks;
    interrupts();

    long avgTicks = (abs(dL) + abs(dR)) / 2;

    if (debugCount++ % 50 == 0) {
      Serial.print("Cell L: ");
      Serial.print(dL);

      Serial.print(" | R: ");
      Serial.print(dR);

      Serial.print(" | Average: ");
      Serial.print(avgTicks);

      Serial.print(" | Target: ");
      Serial.println(CELL_TICKS);
    }

    // Full cell distance completed
    if (avgTicks >= CELL_TICKS) {
      arrived = true;
      break;
    }

    // A wall was detected before finishing the cell
    if (frontDist < FRONT_STOP) {
      statusText = "BLOCKED";
      arrived = false;
      break;
    }

    int wallCorr = getWallCorrection();

    float error = dL + dR;

    // Ignore very small encoder error
    if (abs(error) < 3) {
      error = 0;
    }

    // Reset integral when error changes direction
    if (error * lastError < 0) {
      integral = 0;
    }

    lastError = error;

    integral += error;
    integral = constrain(integral, -20.0f, 20.0f);

    float derivative = error - prevError;

    float correction =
        (Kp * error) +
        (Ki * integral) +
        (Kd * derivative) +
        BASE_CORRECTION +
        wallCorr;

    correction = constrain(
        correction,
        -(float)MAX_CORRECTION,
        (float)MAX_CORRECTION
    );

    int leftSpeed = constrain(
        BASE_SPEED - (int)correction,
        MIN_SPEED,
        255
    );

    int rightSpeed = constrain(
        BASE_SPEED + (int)correction,
        MIN_SPEED,
        255
    );

    setMotor(leftSpeed, rightSpeed);

    prevError = error;

    delay(20);
  }

  stopMotorsOnly();
  motionActive = false;

  if (arrived && !abortFlag) {
    wallAlignment();
    statusText = "CELL DONE";
    return true;
  }

  if (abortFlag) {
    statusText = "MOVEMENT ABORTED";
  }

  return false;
}

// Allows the web STOP command to work during a turn
bool runTurnForTime(int durationMs) {
  unsigned long startTime = millis();

  while ((millis() - startTime) < durationMs) {
    server.handleClient();

    if (abortFlag) {
      stopMotorsOnly();
      return false;
    }

    delay(5);
  }

  return true;
}

bool pivotLeft() {
  stopMotorsOnly();
  delay(100);

  resetEncoders();

  motionActive = true;
  statusText = "TURNING LEFT";

  setMotor(-TURN_SPEED, TURN_SPEED);

  bool completed = runTurnForTime(TURN_DELAY_LEFT);

  stopMotorsOnly();
  delay(150);

  if (!completed || abortFlag) {
    motionActive = false;
    statusText = "LEFT ABORTED";
    return false;
  }

  postTurnCalibration();

  motionActive = false;
  statusText = "LEFT DONE";

  return true;
}

bool pivotRight() {
  stopMotorsOnly();
  delay(100);

  resetEncoders();

  motionActive = true;
  statusText = "TURNING RIGHT";

  setMotor(TURN_SPEED, -TURN_SPEED);

  bool completed = runTurnForTime(TURN_DELAY_RIGHT);

  stopMotorsOnly();
  delay(150);

  if (!completed || abortFlag) {
    motionActive = false;
    statusText = "RIGHT ABORTED";
    return false;
  }

  postTurnCalibration();

  motionActive = false;
  statusText = "RIGHT DONE";

  return true;
}

bool pivot180() {
  stopMotorsOnly();
  delay(100);

  resetEncoders();

  motionActive = true;
  statusText = "TURNING 180";

  setMotor(TURN_SPEED, -TURN_SPEED);

  bool completed = runTurnForTime(TURN_DELAY_180);

  stopMotorsOnly();
  delay(150);

  if (!completed || abortFlag) {
    motionActive = false;
    statusText = "180 ABORTED";
    return false;
  }

  postTurnCalibration();

  motionActive = false;
  statusText = "180 DONE";

  return true;
}

void turnLeft90() {
  if (pivotLeft()) {
    robotDir = (robotDir + 3) & 3;
    statusText = "LEFT DONE";
  }
}

void turnRight90() {
  if (pivotRight()) {
    robotDir = (robotDir + 1) & 3;
    statusText = "RIGHT DONE";
  }
}

void turn180() {
  if (pivot180()) {
    robotDir = (robotDir + 2) & 3;
    statusText = "180 DONE";
  }
}

bool inMaze(int x, int y) {
  return x >= 0 && x < MAZE &&
         y >= 0 && y < MAZE;
}

bool hasWall(int x, int y, int dir) {
  if (!inMaze(x, y) || dir < 0 || dir > 3) {
    return true;
  }

  return (wallsGrid[y][x] & (1 << dir)) != 0;
}

void setWall(int x, int y, int dir) {
  if (!inMaze(x, y) || dir < 0 || dir > 3) {
    return;
  }

  wallsGrid[y][x] |= (1 << dir);

  int nx = x + DX[dir];
  int ny = y + DY[dir];

  // Add the opposite wall to the neighboring cell
  if (inMaze(nx, ny)) {
    int oppositeDir = (dir + 2) & 3;
    wallsGrid[ny][nx] |= (1 << oppositeDir);
  }
}

// Dynamic center goal based on maze size
bool isCenterGoal(int x, int y) {
  int centerLow  = (MAZE - 1) / 2;
  int centerHigh = MAZE / 2;

  // Odd-sized maze: one center cell
  if (MAZE % 2 == 1) {
    return x == centerHigh &&
           y == centerHigh;
  }

  // Even-sized maze: four center cells
  return (x == centerLow || x == centerHigh) &&
         (y == centerLow || y == centerHigh);
}

bool isFullyMapped() {
  for (int y = 0; y < MAZE; y++) {
    for (int x = 0; x < MAZE; x++) {
      if (!visitedGrid[y][x]) {
        return false;
      }
    }
  }

  return true;
}

int getMappedCount() {
  int count = 0;

  for (int y = 0; y < MAZE; y++) {
    for (int x = 0; x < MAZE; x++) {
      if (visitedGrid[y][x]) {
        count++;
      }
    }
  }

  return count;
}

void resetMaze() {
  for (int y = 0; y < MAZE; y++) {
    for (int x = 0; x < MAZE; x++) {
      wallsGrid[y][x] = 0;
      visitedGrid[y][x] = false;
      floodGrid[y][x] = 255;
      pathGrid[y][x] = 255;
    }
  }

  // Add outer maze walls
  for (int i = 0; i < MAZE; i++) {
    setWall(i, 0, 2);          // South wall
    setWall(i, MAZE - 1, 0);   // North wall
    setWall(0, i, 3);          // West wall
    setWall(MAZE - 1, i, 1);   // East wall
  }

  robotX = 0;
  robotY = 0;
  robotDir = 0;

  startX = 0;
  startY = 0;
  startDir = 0;

  mazeMapped = false;
  statusText = "MAZE RESET";

  Serial.println(
    "=== MAZE RESET: " +
    String(MAZE) + "x" +
    String(MAZE) + " ==="
  );
}

// flood fill
void floodFill(bool toStart, bool onlyVisited) {
  uint8_t qx[MAZE * MAZE];
  uint8_t qy[MAZE * MAZE];

  int head = 0;
  int tail = 0;

  // Reset all flood values
  for (int y = 0; y < MAZE; y++) {
    for (int x = 0; x < MAZE; x++) {
      floodGrid[y][x] = 255;
    }
  }

  // Flood toward the starting cell
  if (toStart) {
    floodGrid[startY][startX] = 0;

    qx[tail] = startX;
    qy[tail] = startY;
    tail++;
  }

  // Flood toward the center goal cells
  else {
    int centerLow  = (MAZE - 1) / 2;
    int centerHigh = MAZE / 2;

    // Odd maze size: one center cell
    if (MAZE % 2 == 1) {
      floodGrid[centerHigh][centerHigh] = 0;

      qx[tail] = centerHigh;
      qy[tail] = centerHigh;
      tail++;
    }

    // Even maze size: four center cells
    else {
      int goalX[4] = {
        centerLow,
        centerHigh,
        centerLow,
        centerHigh
      };

      int goalY[4] = {
        centerLow,
        centerLow,
        centerHigh,
        centerHigh
      };

      for (int i = 0; i < 4; i++) {
        floodGrid[goalY[i]][goalX[i]] = 0;

        qx[tail] = goalX[i];
        qy[tail] = goalY[i];
        tail++;
      }
    }
  }

  // Breadth-first search
  while (head < tail) {
    int x = qx[head];
    int y = qy[head];
    head++;

    for (int d = 0; d < 4; d++) {
      // Do not cross a known wall
      if (hasWall(x, y, d)) {
        continue;
      }

      int nx = x + DX[d];
      int ny = y + DY[d];

      if (!inMaze(nx, ny)) {
        continue;
      }

      // When requested, use only visited cells
      if (
        onlyVisited &&
        !visitedGrid[ny][nx] &&
        !(nx == robotX && ny == robotY)
      ) {
        continue;
      }

      // Cell was already assigned a flood value
      if (floodGrid[ny][nx] != 255) {
        continue;
      }

      floodGrid[ny][nx] = floodGrid[y][x] + 1;

      qx[tail] = nx;
      qy[tail] = ny;
      tail++;
    }
  }

  Serial.println("=== FLOOD FILL RESULTS ===");

  Serial.print("Robot at (");
  Serial.print(robotX);
  Serial.print(",");
  Serial.print(robotY);
  Serial.println(")");

  Serial.print("Flood value: ");
  Serial.println(floodGrid[robotY][robotX]);
}

void findShortestPath() {
  // Clear any old path
  for (int y = 0; y < MAZE; y++) {
    for (int x = 0; x < MAZE; x++) {
      pathGrid[y][x] = 255;
    }
  }
  floodFill(false, true);

  int x = startX;
  int y = startY;
  int step = 0;

  while (
    !isCenterGoal(x, y) &&
    step < MAZE * MAZE
  ) {
    int bestDir = -1;
    int bestVal = 255;

    for (int d = 0; d < 4; d++) {
      if (hasWall(x, y, d)) {
        continue;
      }

      int nx = x + DX[d];
      int ny = y + DY[d];

      if (!inMaze(nx, ny)) {
        continue;
      }

      // Speed run must stay in mapped cells
      if (!visitedGrid[ny][nx] &&
          !isCenterGoal(nx, ny)) {
        continue;
      }

      if (floodGrid[ny][nx] < bestVal) {
        bestVal = floodGrid[ny][nx];
        bestDir = d;
      }
    }

    if (bestDir < 0 || bestVal == 255) {
      Serial.println(
        "ERROR: No valid mapped path to center"
      );
      break;
    }

    pathGrid[y][x] = bestDir;

    x += DX[bestDir];
    y += DY[bestDir];

    step++;
  }

  // Mark the final goal cell as the end of the path
  if (inMaze(x, y)) {
    pathGrid[y][x] = 255;
  }

  Serial.println("=== SHORTEST PATH FOUND ===");

  Serial.print("Path length: ");
  Serial.println(step);

  if (!isCenterGoal(x, y)) {
    Serial.println(
      "WARNING: Path did not reach the center"
    );
  }
}
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
void loop() {
  server.handleClient();
  if (runMode != MODE_IDLE && !abortFlag) {
    solverStep();
  }
  delay(20);
}
